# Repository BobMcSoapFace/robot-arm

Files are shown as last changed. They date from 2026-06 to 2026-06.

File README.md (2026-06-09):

# robot-arm
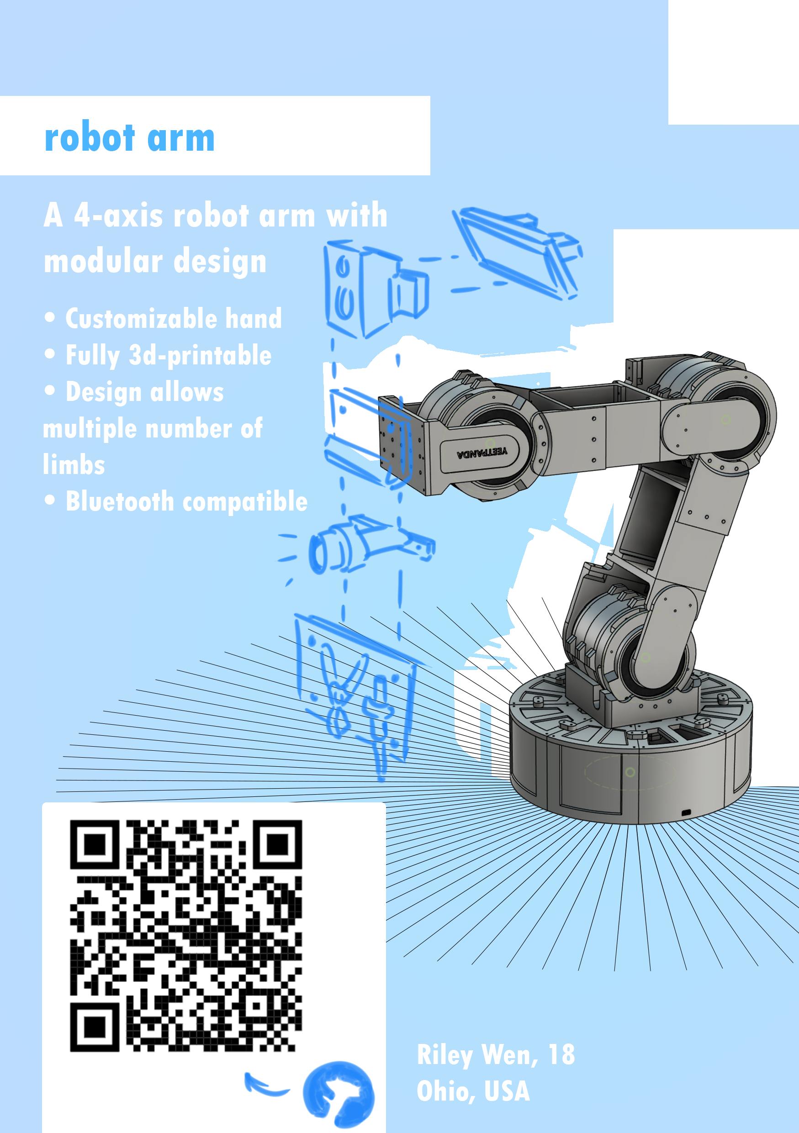
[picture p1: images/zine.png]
zine picture

robot-arm is a 4-axis robot arm designed with modularity in mind. Depending on the maximum torque output of the motors and maximum range of the I2C wires, this project can support numerous limbs with only minor changes in code. Currently, the code is fixed to allowing two limbs and a hand on the robot.

I built this project mostly to challenge myself to tackle more complicated electronic and mechanical designs, but also because most hobbyist robot arms focus on using claws or grippers to pick up objects. For this project, the minor change of a claw to a hand that can sense its own orientation as well as high gear ratios allows for supporting heavier objects such as displays and light fixtures. 

All materials can be found within BOM.csv.
# Electronics
## Limb Controller PCB
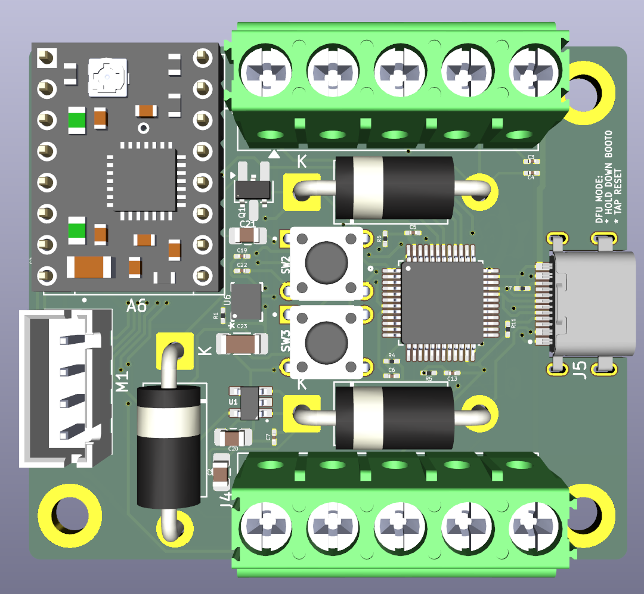
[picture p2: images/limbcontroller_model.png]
limb controller pcb 3d model

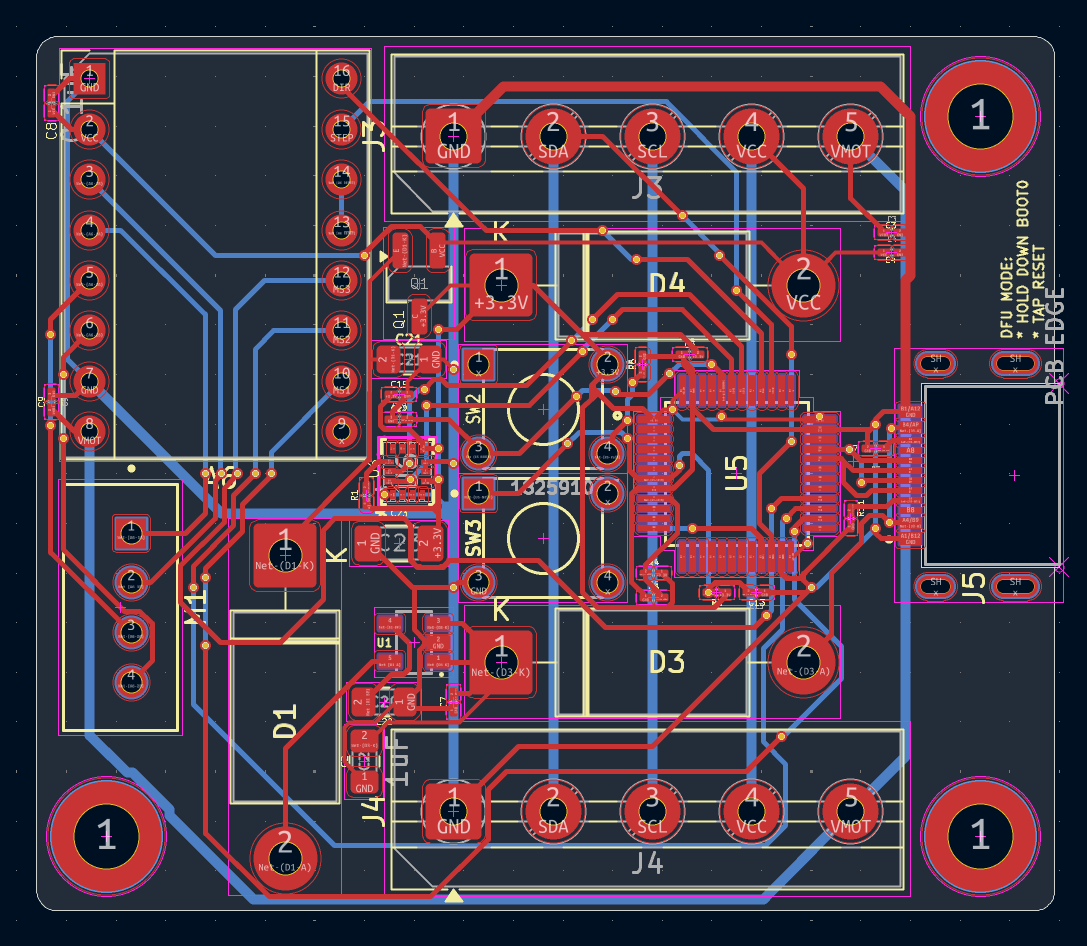
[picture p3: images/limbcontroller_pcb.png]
limb controller pcb footprint

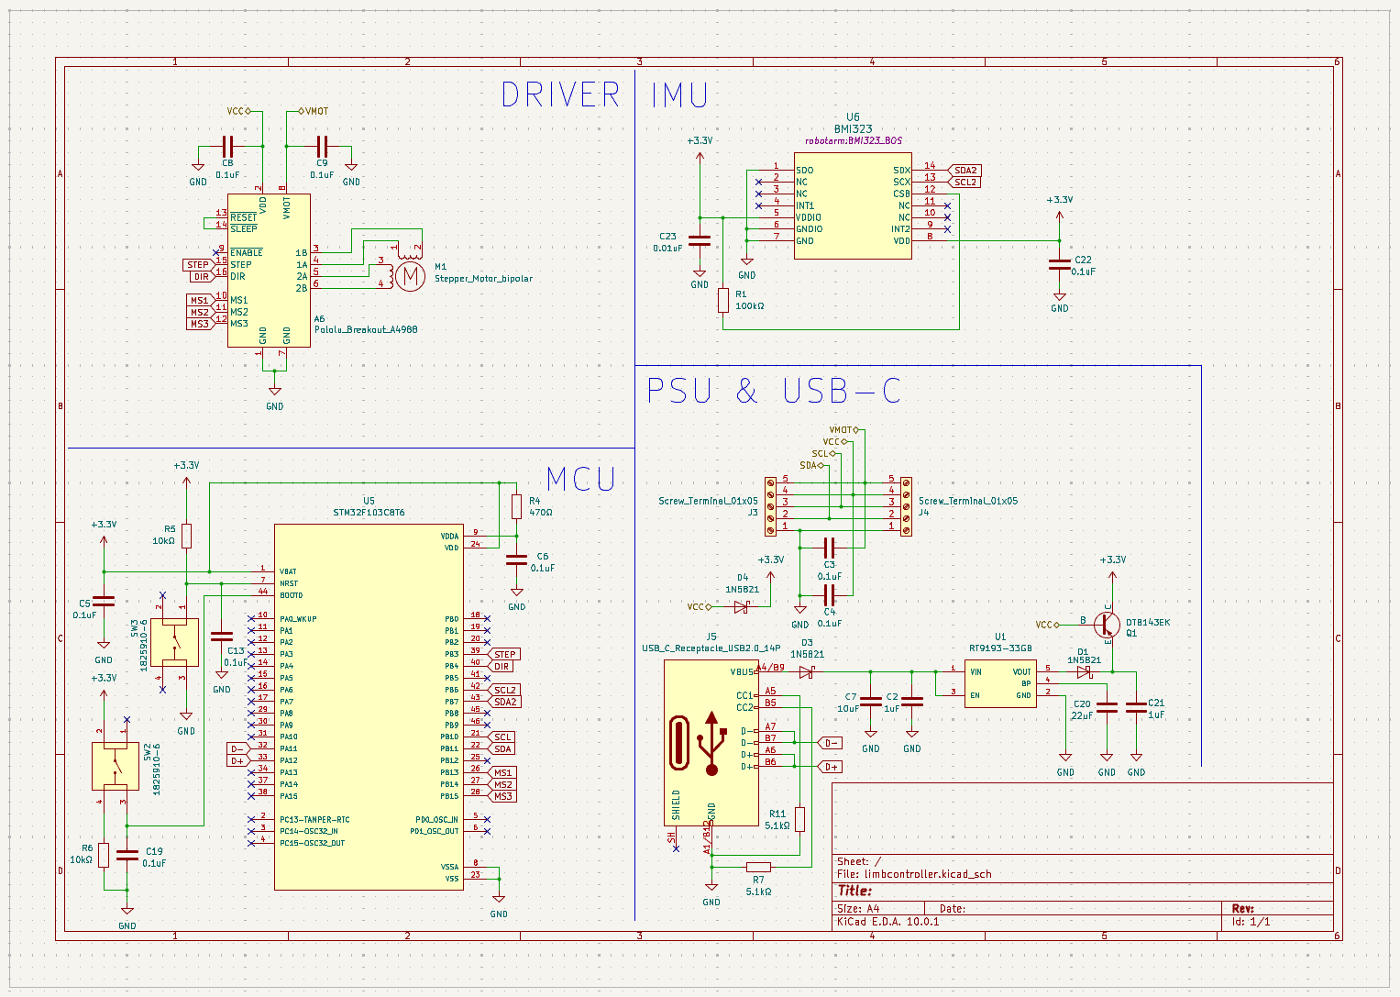
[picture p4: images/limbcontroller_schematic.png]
limb controller schematic

## Main Controller PCB
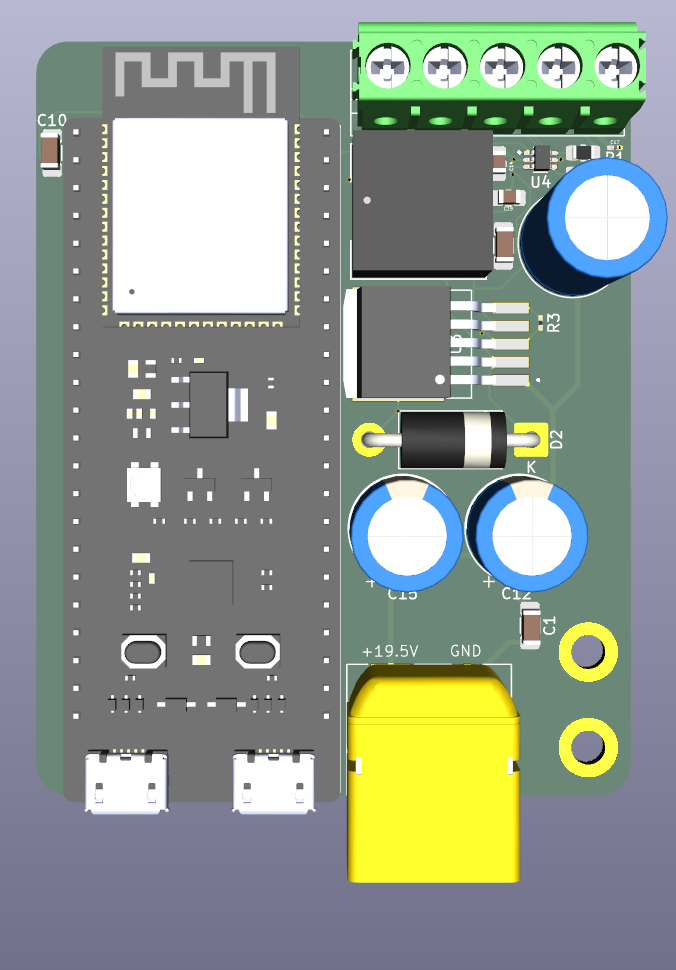
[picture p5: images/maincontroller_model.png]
main controller pcb 3d model

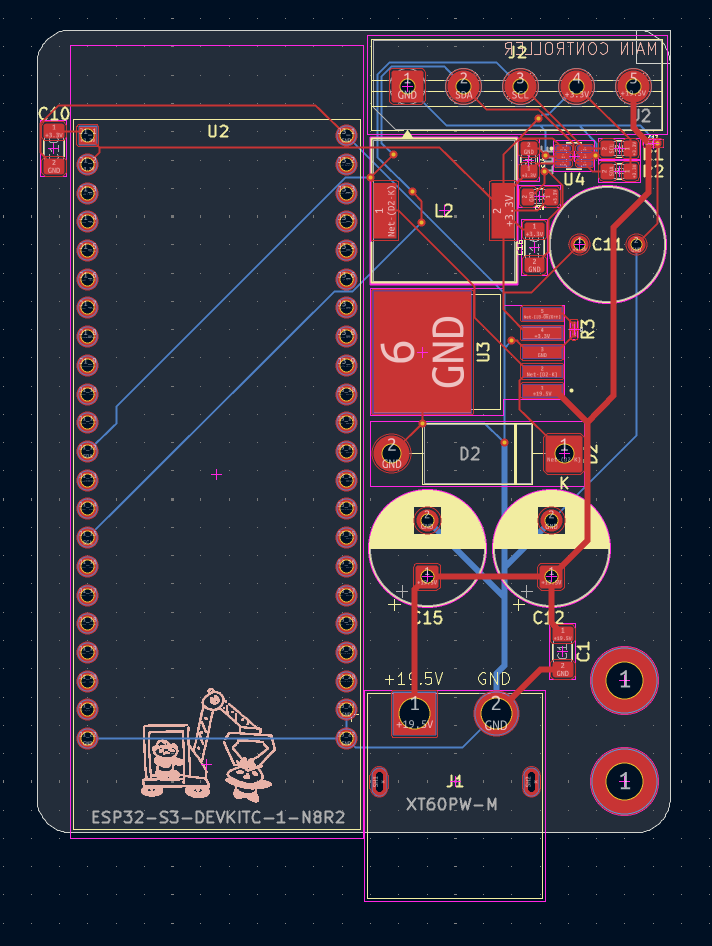
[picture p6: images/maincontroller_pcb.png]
main controller pcb footprint

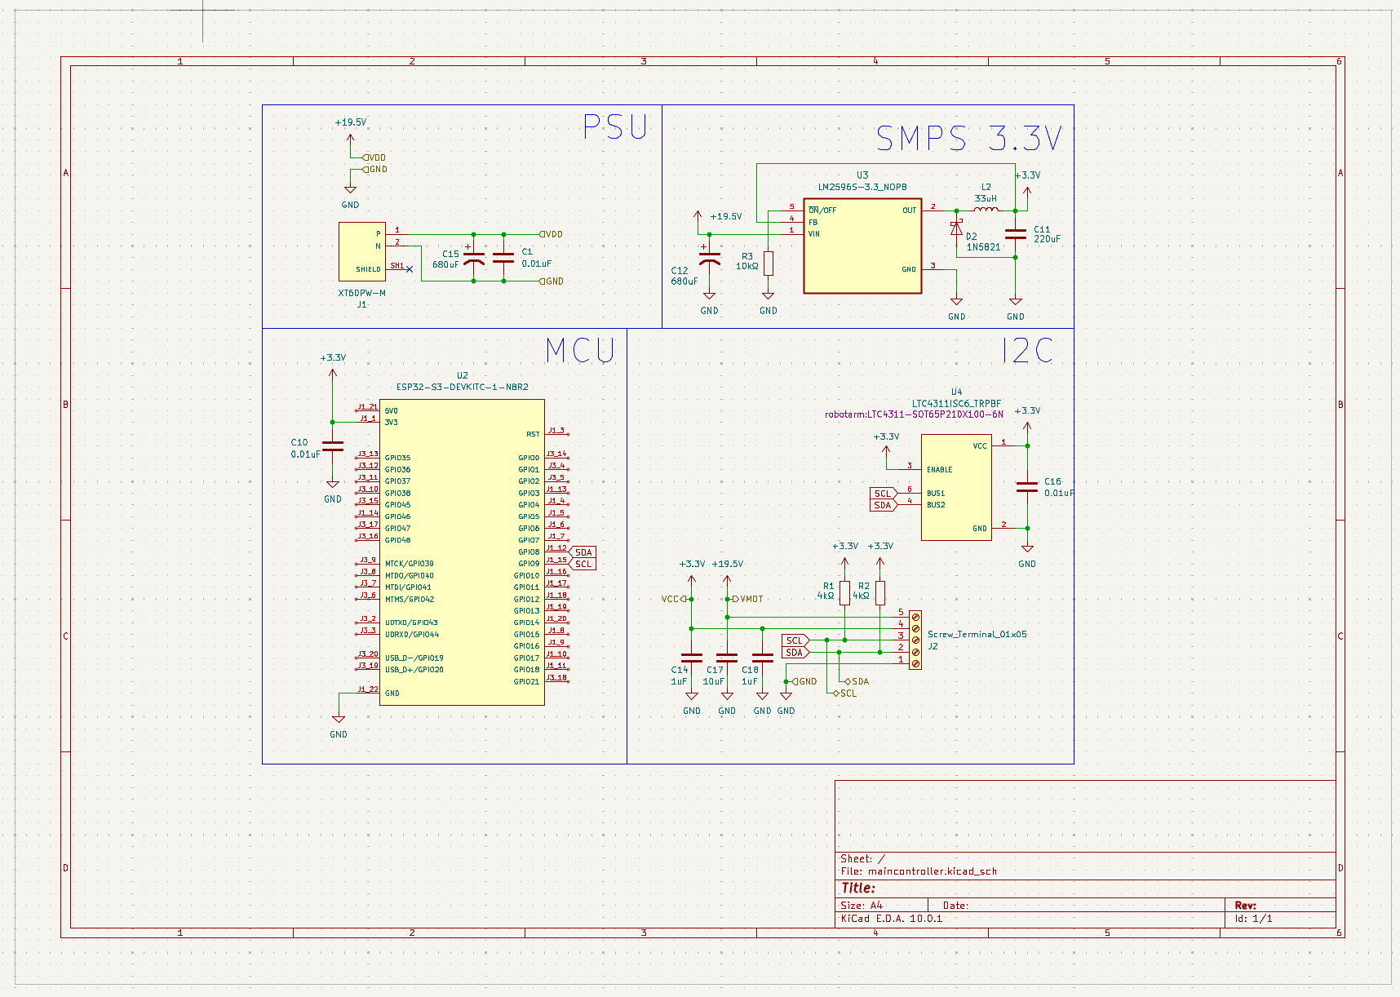
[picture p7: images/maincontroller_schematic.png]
main controller schematic

# Setup Instructions
## Electronics
First solder the components onto each board based on the diagrams above. For this project only 1 of the main controller boards are required, however 5 limb controller boards are required as well (with 1 not requiring a corresponding stepper motor nor driver).

On the main controller board, use PlatformIO to flash the main controller board using the code in /code/MainController. Since the board runs on an ESP32, flashing using other tools is likely be supported. Do not connect the XT60 while simultaneously flashing.

On the limb controller boards, use PlatformIO to flash via USB-C. While USB-C is connected, hold down the BOOT0 button and press the NRST button to enter DFU mode. Adjust the two parameters listed in the program based on which gearBox the controller is intended to be used for. Then, flash the firmware in /code/LimbController. 

## Assembly
Unless specified otherwise, all screws mentioned in the steps below refer to M4 1.6cm long screws meant for M4x6x6 inserts.
### Step 1 - baseSunGear
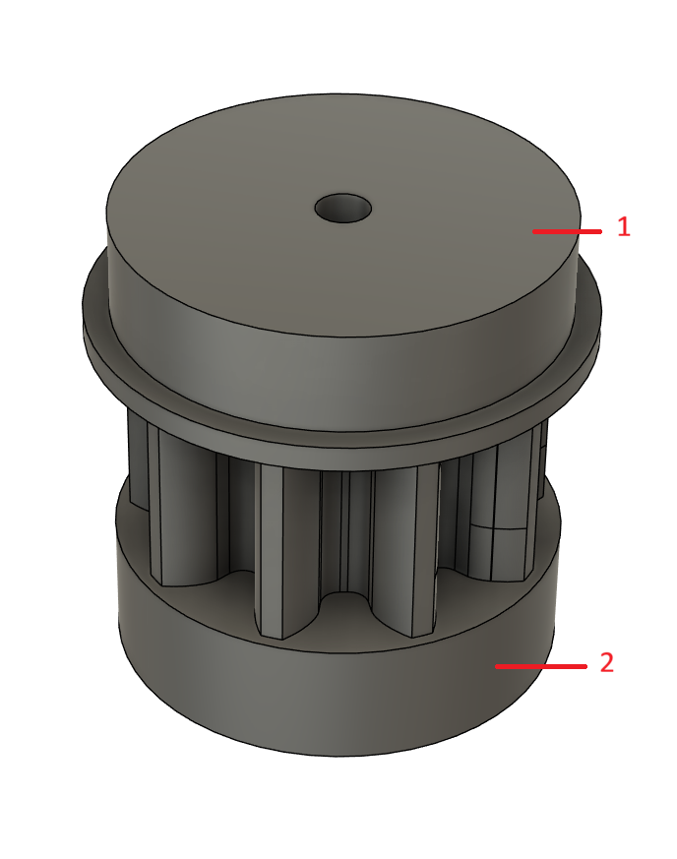
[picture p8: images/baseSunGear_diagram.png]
baseSunGear diagram

| Object | Print Quantity |
| --- | --- |
| 1 | 1x1 |
| 2 | 1x1 |
\* The "xN" represents the total number of gearboxes that require this part (meaning that a 3x4 quantity will need to be printed 12 times total)
1. For every hole about 0.7cm in diameter in every printable part, insert a M4x6x6 heat set threaded insert. 
   * In this part, only 1 threaded insert is required (the attachment between part 1 and part 2)
2. Screw part 1 to part 2.
3. Repeat this process 3 more times, for a total baseSunGear quantity of 4.
### Step 2 - gearReducer
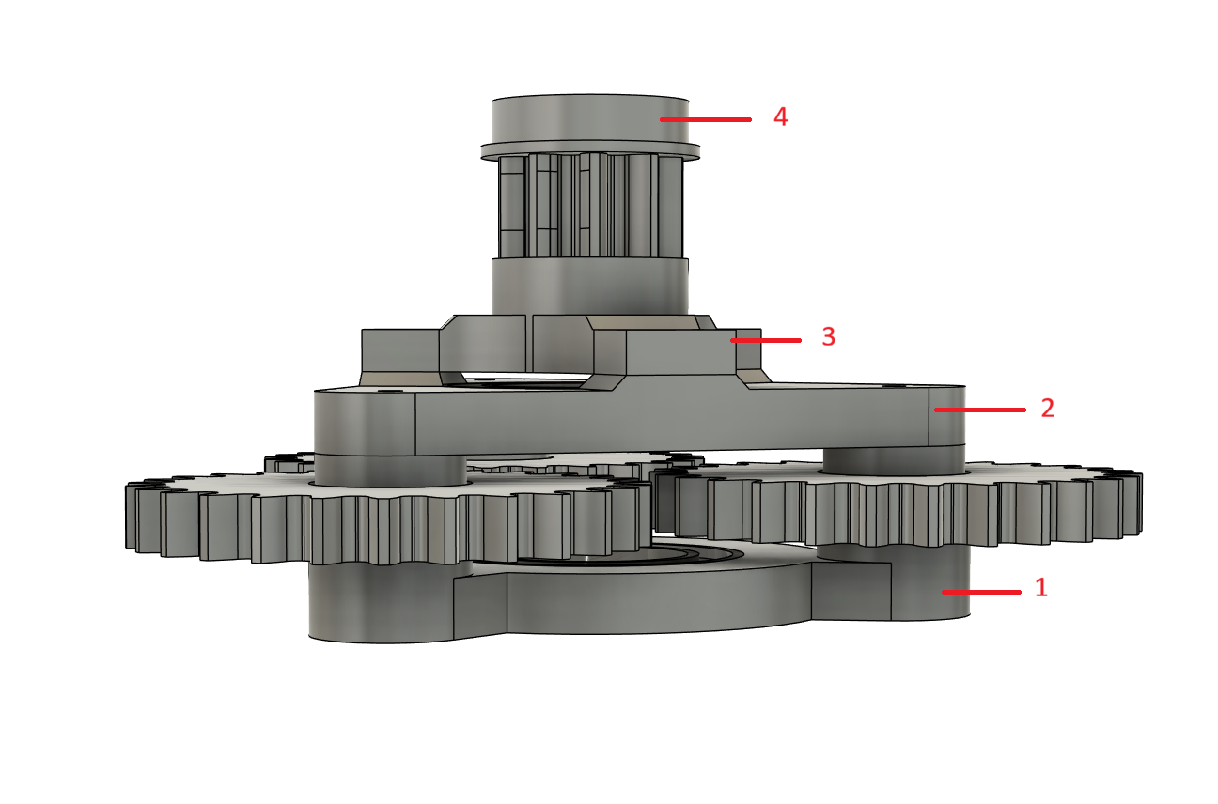
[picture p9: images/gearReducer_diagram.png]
gearReducer diagram

<ins>**Note: There is a baseSunGear supposed to be between parts 1 and 2 and the three gears, but is hidden for better clarity.**</ins>
| Object | Print Quantity |
| --- | --- |
| 1 | 1x4 |
| 2 | 1x4 |
| 3 | 1x4 |
| 4 | 1x4 |
| Gear (27 teeth) | 3x4 |
\* The "xN" represents the total number of gearboxes that require this part (meaning that a 3x4 quantity will need to be printed 12 times total)

1. For every hole about 0.7cm in diameter in every printable part, insert a M4x6x6 heat set threaded insert. 
2. Using a hammer or other means, press fit a 6907ZZ bearing into part 1.
3. For each of the three 27 tooth gears, press fit a 6805 bearing into its cavity.
4. With the smaller hole side facing upwards, place each of the 3 gears on the poles of part 1.
5. Press fit a 6907ZZ bearing into the center hole of part 2.
6. With the baseSunGear's circular side of its part 2, press fit the baseSunGear into the 6907ZZ bearing of part 1 (the baseSunGear protruding upwards and aligning its teeth with the three gears).
7. Press fit part 2's 6907ZZ bearing on the baseSunGear's part 1.
7. Screw part 2 to part 1.
8. Screw part 3 to part 2.
9. Screw part 4 to part 3.
10. Repeat this process 3 more times, for a total gearReducer quantity of 4.
### Step 3 - gearReducerOutput
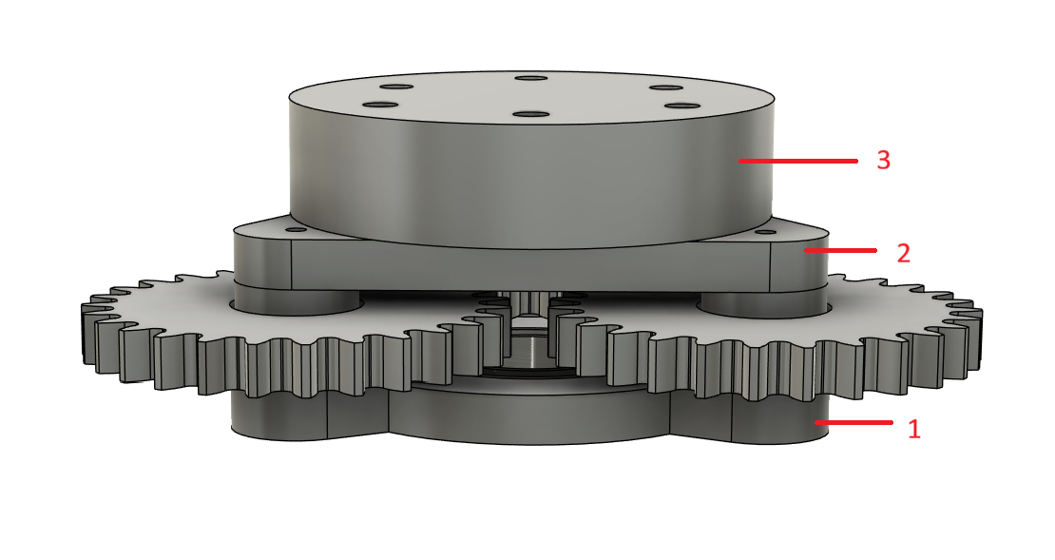
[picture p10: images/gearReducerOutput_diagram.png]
gearReducerOutput digram

| Object | Print Quantity |
| --- | --- |
| 1 | 1x4 |
| 2 | 1x4 |
| 3 | 1x4 |
| Gear (27 teeth) | 3x4 |
\* The "xN" represents the total number of gearboxes that require this part (meaning that a 3x4 quantity will need to be printed 12 times total)
1. For every hole about 0.7cm in diameter in every printable part, insert a M4x6x6 heat set threaded insert. 
2. Using a hammer or other means, press fit a 6907ZZ bearing into part 1.
3. For each of the three 27 tooth gears, press fit a 6805 bearing into its cavity.
4. With the smaller hole side facing upwards, place each of the 3 gears on the poles of part 1.
5. Press fit a 6907ZZ bearing into the center hole of part 2.
6. Screw part 2 to part 1.
7. Screw part 3 to part 2.
9. Repeat this process 3 more times, for a total gearReducerOutput quantity of 4.
### Step 4 - gearBox
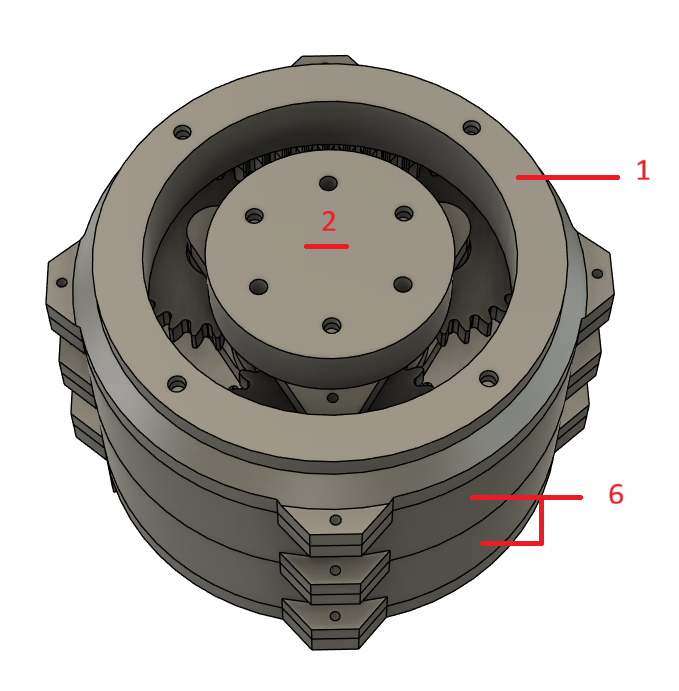
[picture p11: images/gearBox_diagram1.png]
gearBox diagram 1

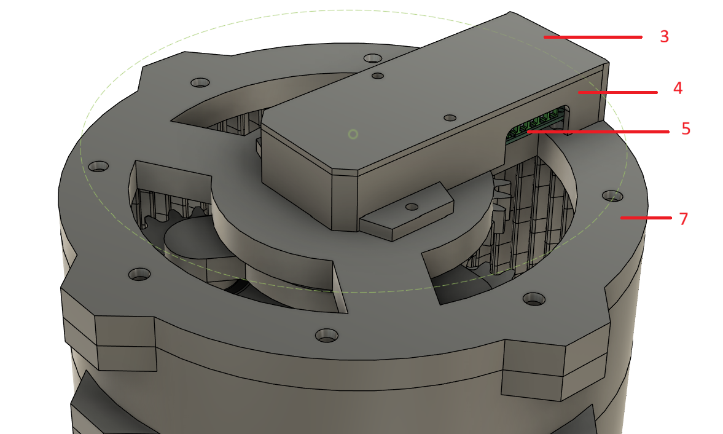
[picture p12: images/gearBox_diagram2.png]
gearBox diagram 2

<ins>**Note: There is a 6020 bearing supposed to be between parts 1 and 2, but is hidden for better clarity.**</ins>
| Object | Print Quantity |
| --- | --- |
| 1 | 1x4 |
| 2 | 1x4 |
| 3 | 1x4 |
| 4 | 1x4 |
| 5 | 1x4 |
| 6 | 2x4 |
| gearReducerOutput | 1x4 |
| gearReducer | 1x4 |
| baseSunGear | 1x4 |
| Nema17 Stepper Motor | 1x4 |

1. For every hole about 0.7cm in diameter in every printable part, insert a M4x6x6 heat set threaded insert. 
2. Screw the two part 6's together using the outer brackets.
3. Screw the joined part 6's to part 7.
4. Screw part 4 to part 7.
5. Screw part 5 to part 7, with the screw terminals being accessible from the provided holes.
6. Align the asymmetrical shaft of the Nema17 stepper motor to the gearReducer's baseSunGear corresponding hole of the same shape, attaching the two objects.
7. Lower the gearReducer with the Nema17 into the ring gears, with the Nema17 aligning with the cavity provided by part 4.
8. Once the Nema17 is inside the cavity, screw part 3 to part 4, blocking the Nema17 from falling through.
9. Unscrew part 4 from part 3 for the gearReducer, and unscrew parts 2 and 3 from gearReducerOutput's part 1.
10. Lower the gearReducerOutput into the ring gear, aligning the 27 teeth gears with the base gear in the middle.
11. Screw back part 4 to part 3 for the gearReducer
12. Press fit the gearReducer's part 4 with the 6907ZZ bearing of the deattached gearReducerOutput's part 2, then screw parts 2 and 3 back to gearReducerOutput's part 1.
13. Press fit a 6020 bearing onto the gearbox's part 1, then press fit the bearing onto the gearReducerOutput's output cylinder (marked part 2)
14. Repeat 3 more times, for a total of 4 gearboxes.
### Step 5 - limb
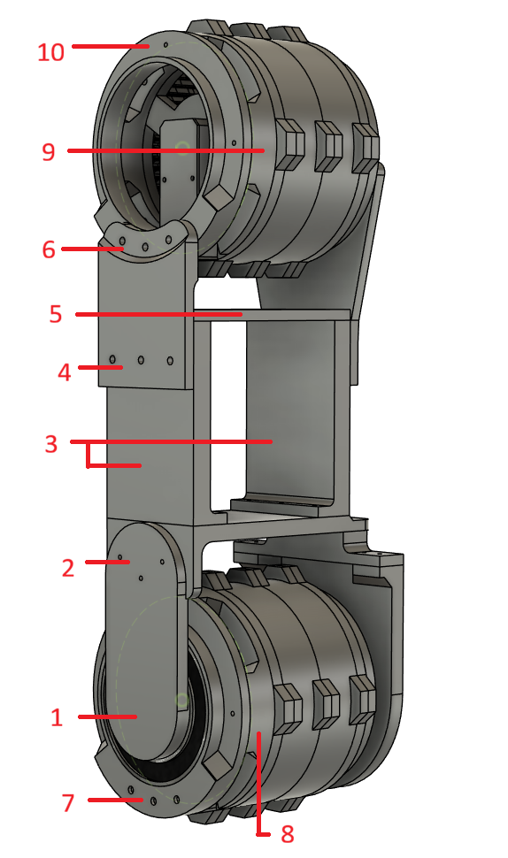
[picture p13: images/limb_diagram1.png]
limb diagram 1

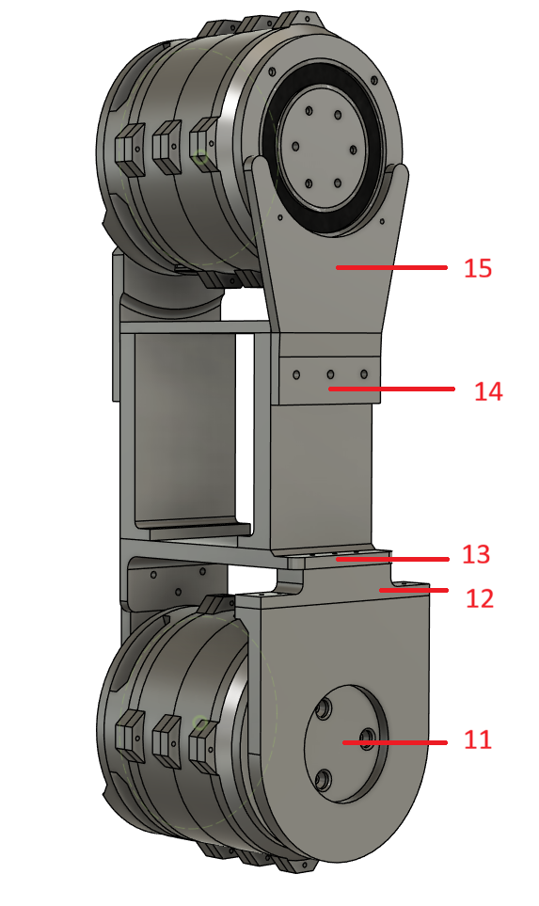
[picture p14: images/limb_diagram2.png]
limb diagram 2

| Object | Print Quantity |
| --- | --- |
| 1 | 1x2 |
| 3 | 2x2 |
| 4 | 1x2 |
| 5 | 1x2 |
| 7 | 1x2 |
| 8 | 1x2 |
| 9 | 1x2 |
| 10 | 1x2 |
| 11 | 1x2 |
| 12 | 1x2 |
| 13 | 1x2 |
| 14 | 1x2 |
\*Note that parts 15 and 6 are the same parts as 14 and 5 respectively.
1. For every hole about 0.7cm in diameter in every printable part, insert a M4x6x6 heat set threaded insert. 
2. On a gearbox, screw part 8 to the side with the controller.
3. Press fit a 6020 bearing to part 7, then screw part 7 to part 8.
4. Press fit part 1 to the bearing.
5. On the side of the gearbox outputting rotation, screw part 11 to the gearbox's output.
6. Screw part 12 to part 11.
7. Screw part 13 to parts 12 and 2.
8. Screw the two part 3's to part 13.
9. Screw part 5 to the two part 3's.
10. Screw part 4 to the part 3 on the side of the gearbox's controller.
11. Screw part 14 to the part 3 on the side of the gearbox's output.
12. Screw parts 14 and 4 to a second gearbox.
13. Repeat the steps above for a second limb, using the newly attached gearbox as the base (used in steps 2 and 5).
### Step 6 - base
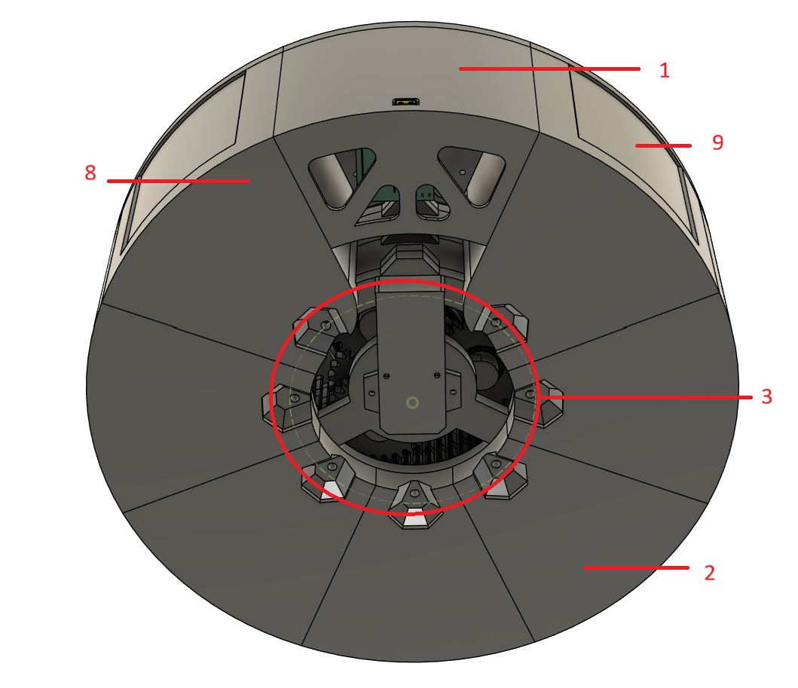
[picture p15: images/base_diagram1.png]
base diagram 1

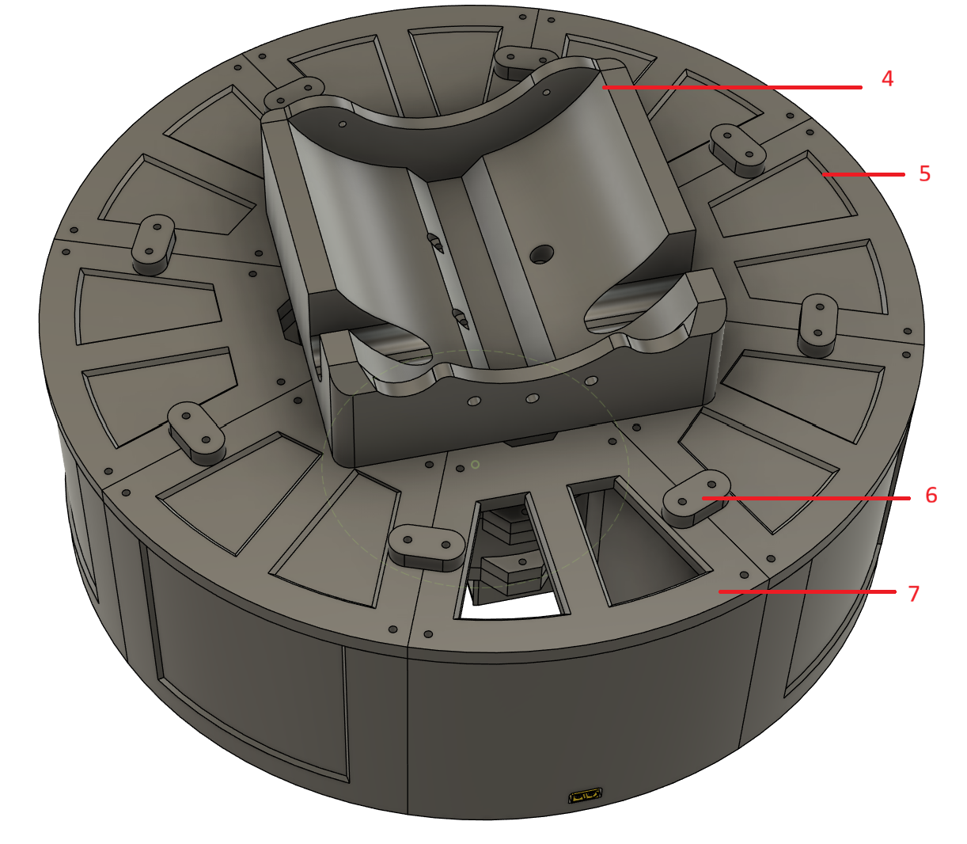
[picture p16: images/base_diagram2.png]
base diagram 2

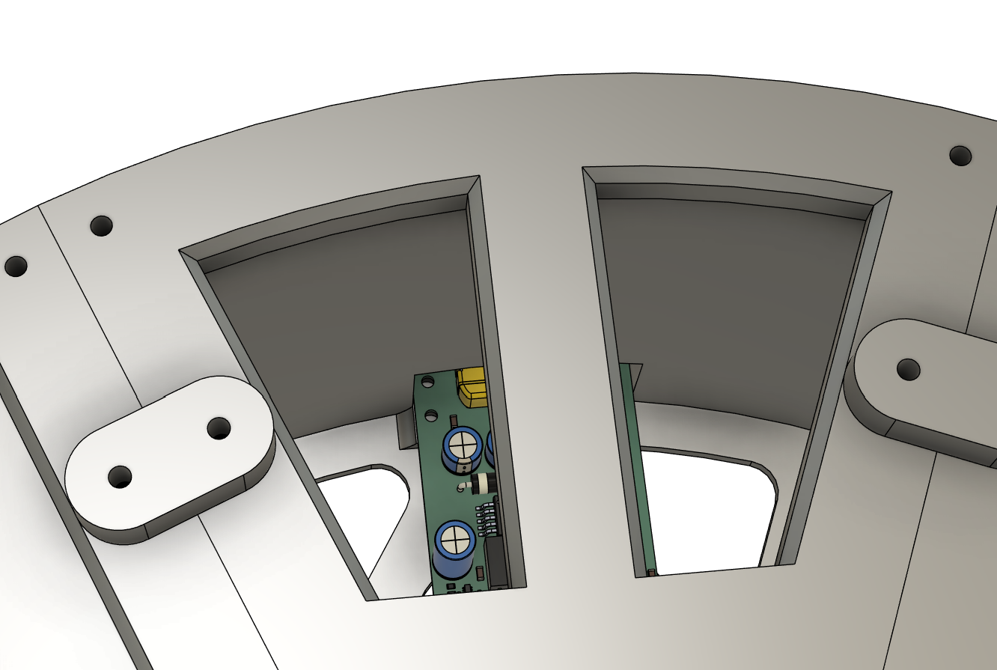
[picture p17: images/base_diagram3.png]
base diagram 3

| Object | Print Quantity |
| --- | --- |
| 1 | 1x1 |
| 2 | 7x1 |
| 4 | 1x1 |
| 5 | 7x1 |
| 6 | 8x1 |
| 7 | 1x1 |
| 8 | 1x1 |
| 9 | 1x1 |

\*Note that parts 15 and 6 are the same parts as 14 and 5 respectively.
1. For every hole about 0.7cm in diameter in every printable part, insert a M4x6x6 heat set threaded insert.
2. Using the inserts indicated by the region labeled #3, screw in 7 part 2's, avoiding the area covered by the gearbox controller.
3. To increase arm stability during movement, insert a heavy filler (e.g sand or gravel) or other similar heavy objects in equal distribution among the part 2's.
4. Screw a part 5 to each of the part 2's (7 total).
5. Screw a main controller PCB to part 1
6. Screw part 1 to the gearbox, and then screw part 7 to part 1.
7. Screw 8 part 6's to connect each of the part 7's together. 
7. With a gearbox in the middle and output side facing upwards, screw part 4 to the gearbox using the three holes.
### Step 7 - hand
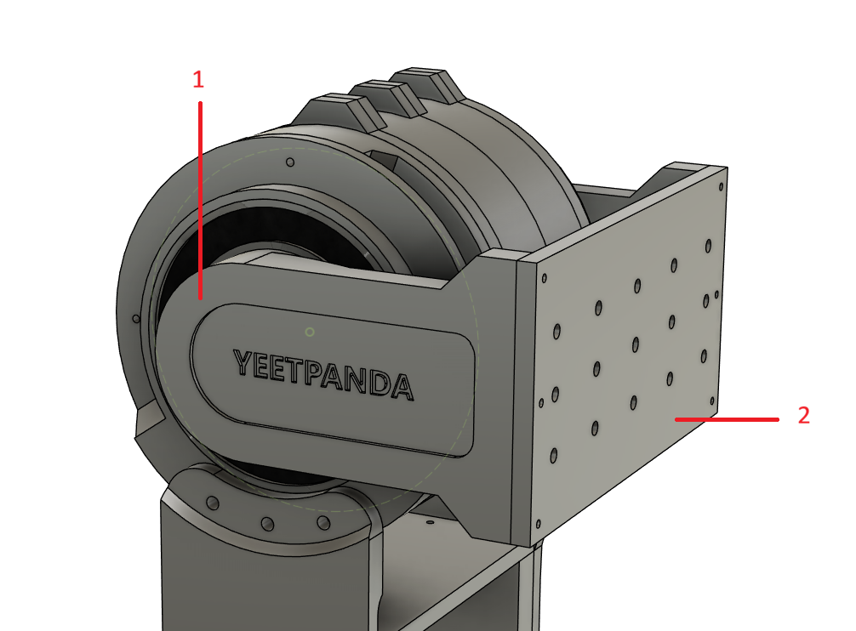
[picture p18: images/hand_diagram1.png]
hand diagram 1

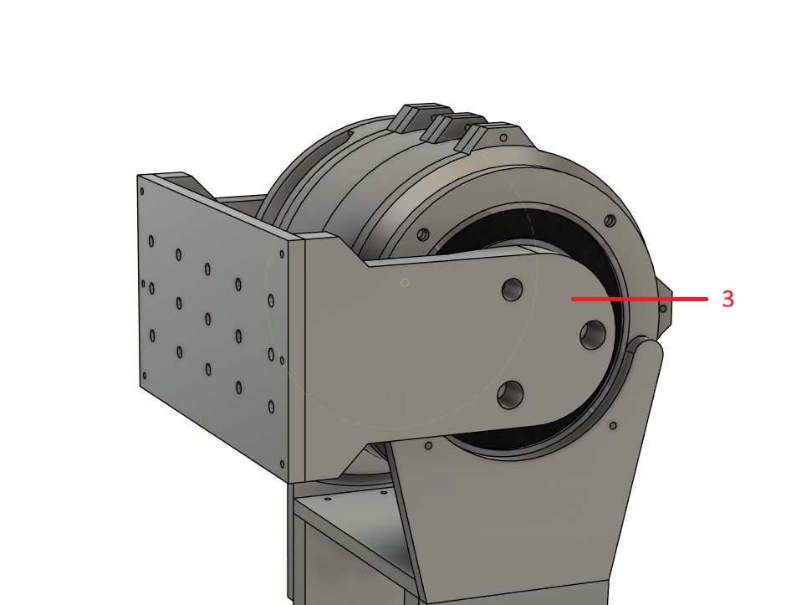
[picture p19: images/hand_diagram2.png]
hand diagram 2

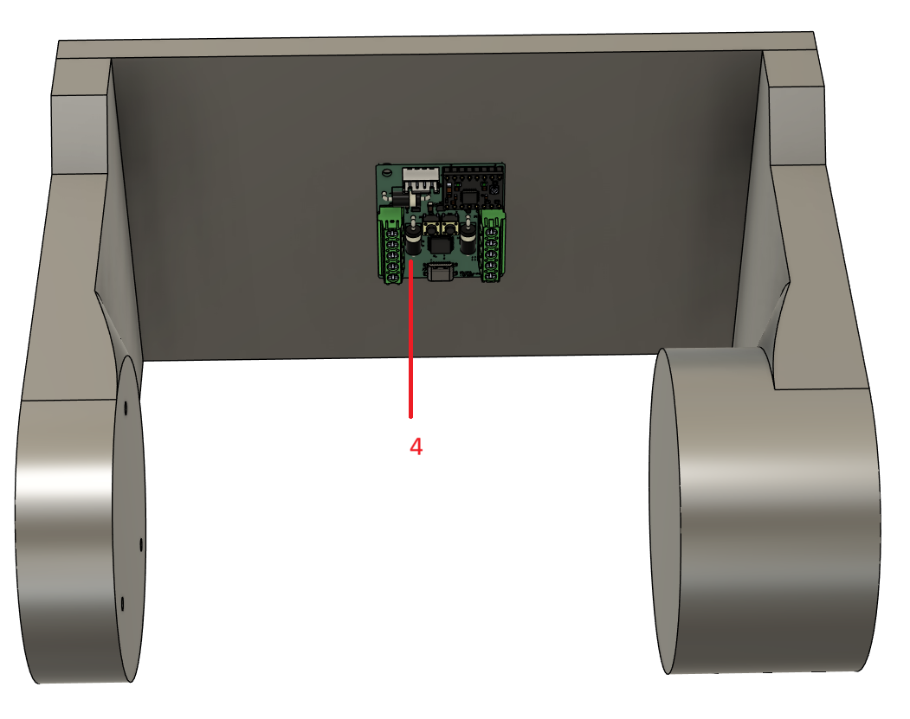
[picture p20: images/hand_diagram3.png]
hand diagram 3


| Object | Print Quantity |
| --- | --- |
| 1 | 1x1 |
| 2 | 1x1 |
| 3 | 1x1 |

1. For every hole about 0.7cm in diameter in every printable part, insert a M4x6x6 heat set threaded insert.
2. Screw part 3 to the output of the last limb's gearbox output.
3. Press fit a 6020 bearing to the last limb's gearbox controller side on the attached part, then press fit part 1 into the bearing.
4. Screw parts 1 and 3 together with part 2.
5. Screw the limb controller (part 4) to part 2.
   * Note that on this controller, an A4988 motor driver is not required.
### Step 8 - Connecting Limbs to Base
1. Using the screw terminals on each board, connect wires from the main controller to the limb controller in the base on one side. On the other side of the limb controller's screw terminals, connect more wires to the next gearbox's limb controllers, repeating the process for each controller until the hand's controller is connected.
   * You may have to unscrew some parts connecting to the gearbox to be able to reach the screw terminals.
   * Low capacitance wires are preferred, ex. solid core
   * Each terminal in the screw terminals on the limb controller are connected directly to the parallel terminal on the other screw terminal; simply connect the same terminals with each other
2. Lower the side of the first limb's initial gearbox with the output side facing the base's part 4 side with two holes for screws.
3. Deattach the limb's part 11 from the gearbox and part 12, then secure the gearbox in the base's part 4 by screwing in the two holes. Reattach part 11 afterwards.
4. On the other side of the gearbox, secure the gearbox with the three screw holes on base 4.

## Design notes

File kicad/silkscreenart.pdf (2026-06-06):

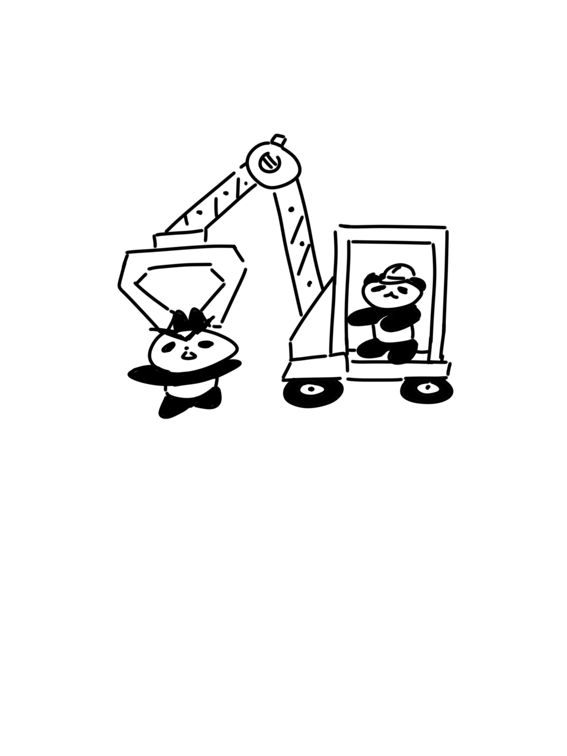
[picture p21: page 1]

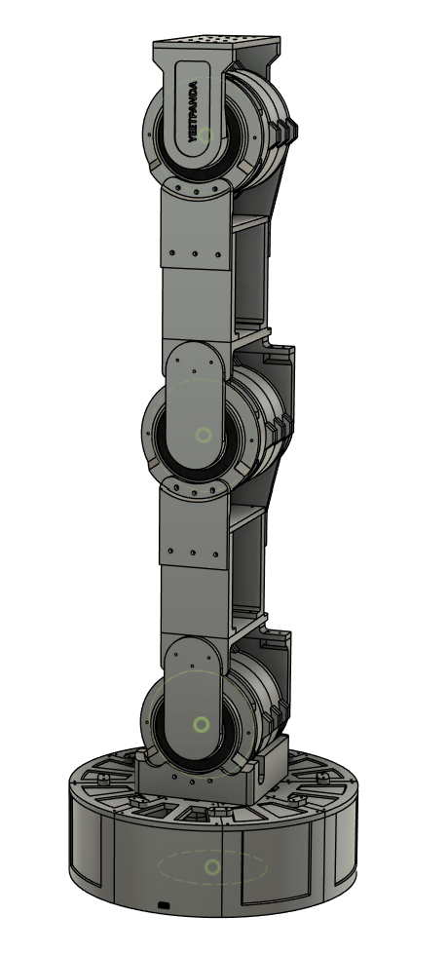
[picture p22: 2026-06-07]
images/arm_diagram2.png

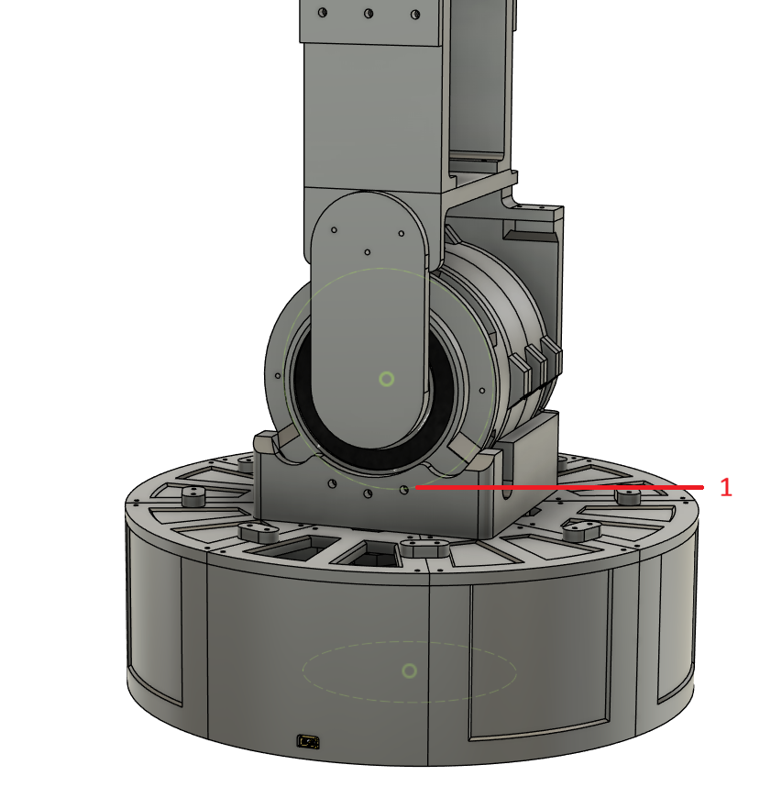
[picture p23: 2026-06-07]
images/arm_diagram1.png

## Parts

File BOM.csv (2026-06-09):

Name | Purchase Quantity | Required Pcs | Link | Unit Price | Total Price
19.5V 10.3A Power Adapter | 1 |  | https://www.amazon.com/TAIFU-Adapter-Compatible-Charger-Balance/dp/B0DNJDK5JN | $21.99 | $21.99
LM2596S-3.3V | 1 |  | https://www.digikey.com/en/products/detail/evvo/LM2596S-3-3-EV/24370077 | $1.31 | $1.31
ESP32 Devkit V1 | 1 |  | https://www.aliexpress.us/item/3256808315965945.html?src=google&gatewayAdapt=glo2usa | $4.09 | $4.09
XT60PW-M (Male) | 1 |  | https://www.aliexpress.us/item/2255799820907812.html?src=google&gatewayAdapt=glo2usa | $3.00 | $3.00
A4988 Stepper Motor Driver | 4 |  | https://www.alibaba.com/product-detail/3D-Printed-A4988-Red-Stepper-Motor_1601242133819.html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 | $0.60 | $2.40
STM32F103C8T7TR | 5 |  | https://www.alibaba.com/product-detail/STM32F103C8T7-MCU-Microcontroller-Integrated-Circuit-New_1601672982059.html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 | $2.20 | $11.00
LTC4311ISC6 TRPBF | 1 |  | https://www.digikey.com/en/products/detail/analog-devices-inc/LTC4311ISC6-TRPBF/1814494 | $5.40 | $5.40
BMI323 | 5 |  | https://www.digikey.com/en/products/detail/bosch-sensortec/BMI323/16719593 | $3.69 | $18.45
PNP Transistor DTB143EKT146 | 5 |  | https://www.digikey.com/en/products/detail/rohm-semiconductor/DTB143EKT146/658864 | $0.57 | $2.85
470 Ohm Resistor | 5 |  | https://www.digikey.com/en/products/detail/rohm-semiconductor/KTR03EZPJ471/2288583?gclsrc=aw.ds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 | $0.15 | $0.75
4k Ohm Resistor | 2 |  | https://www.digikey.com/en/products/detail/stackpole-electronics-inc/RNCF0805BTS4K00/9690208 | $0.15 | $0.30
5.1k Ohm Resistor | 10 |  | https://www.digikey.com/en/products/detail/yageo/RC0603FR-075K1L/727268 | $0.10 | $1.00
10k Ohm Resistor | 11 |  | https://www.digikey.com/en/products/detail/yageo/RC0603FR-0710KL/726880 | $0.10 | $1.10
100k Ohm Resistor | 5 |  | https://www.digikey.com/en/products/detail/stackpole-electronics-inc/RGC0603FTC100R/1715582?gclsrc=aw.ds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 | $0.14 | $0.70
1N5821 Diode | 16 |  | https://www.digikey.com/en/products/detail/taiwan-semiconductor-corporation/1N5821/7366595 | $0.71 | $11.36
SPST Switch | 10 |  | https://www.digikey.com/en/products/detail/te-connectivity-alcoswitch-switches/1825910-6/1632536 | $0.13 | $1.30
0.01uF Capacitor | 8 |  | https://www.digikey.com/en/products/detail/kemet/C1206C103K1RACTU/411235 | $0.17 | $1.36
0.1uF Capacitor | 45 |  | https://www.digikey.com/en/products/detail/samsung-electro-mechanics/CL10B104KB8NNNC/3886658 | $0.02 | $0.68
1uF Capacitor | 12 |  | https://www.digikey.com/en/products/detail/murata-electronics/GRM155R61E105KA12D/4905139 | $0.03 | $0.35
10uF Capacitor | 6 |  | https://www.digikey.com/en/products/detail/kyocera-avx/CM105X6S106M25AT/17827475?gclsrc=aw.ds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 | $0.35 | $2.10
22uF Capacitor | 5 |  | https://www.digikey.com/en/products/detail/murata-electronics/GRM21BR61E226ME44K/4905534?gclsrc=aw.ds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 | $0.35 | $1.75
680uF Polarized Capacitor | 2 |  | https://www.digikey.com/en/products/detail/kyocera-avx/REF1020681M025K/20096679?gclsrc=aw.ds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 | $0.62 | $1.24
220uF Capacitor | 1 |  | https://www.digikey.com/en/products/detail/tdk/B41856C6227M000/6159972?gclsrc=aw.ds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 | $0.76 | $0.76
33uH Inductor | 1 |  | https://www.digikey.com/en/products/detail/eaton-electronics-division/DR127-330-R/667173 | $0.85 | $0.85
17HS4401S Nema 17 Stepper Motor | 4 |  | https://www.alibaba.com/product-detail/Hanpose-Stepper-Motor-40N-cm-1_1600212040912.html | $4.50 | $18.00
USB-C Receptacle | 5 |  | https://www.digikey.com/en/products/detail/wec/2340901-1/18856002 | $0.42 | $2.10
RT9193 | 5 |  | https://www.digikey.com/en/products/detail/richtek-usa-inc/RT9193-33GB/2470048 | $0.41 | $2.05
5x1 Screw Terminal | 11 |  | https://www.digikey.com/en/products/detail/phoenix-contact/1935190/568617 | $1.28 | $14.08
B4B-XH-A | 4 |  | https://www.digikey.com/en/products/detail/jst-sales-america-inc/B4B-XH-A/1651047 | $0.17 | $0.68
100pcs M4x6x6 Heat Threaded Inserts | 3 | 279 | https://www.amazon.com/Aoserge-100Pcs-Brass-Heat-Inserts/dp/B0FM3XZZ56?adgrpid=187992247084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 | $6.49 | $19.47
10pcs 6805-2RS | 3 | 24 | https://www.amazon.com/6805-2RS-Bearings-Miniature-Section-Bearing/dp/B0DS59TSHD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 | $12.49 | $37.47
10pcs 6907ZZ Deep Groove Ball Bearings | 2 | 16 | https://www.amazon.com/HiPicco-6907ZZ-Bearings-Shielded-Pre-Lubricated/dp/B0CRLF5NZY?s=industrial | $21.89 | $43.78
6020-2RS | 6 | 6 | https://www.amazon.com/80x125x22mm-Pre-Lubricated-Performance-Effective-Bearings/dp/B0CGLRM1JS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 | $19.99 | $119.94
Total Electrical Parts Price |  |  |  |  | $132.99
Total Mechanical Parts Price |  |  |  |  | $220.66
Total Price |  |  |  |  | $353.65

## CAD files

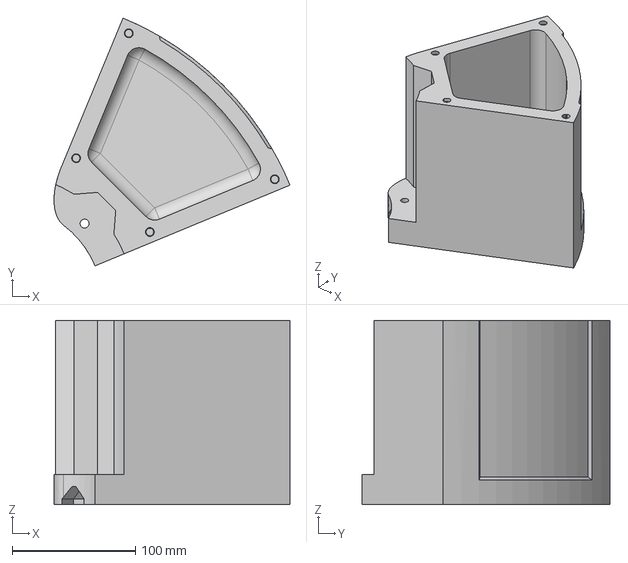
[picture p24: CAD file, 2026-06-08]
model/base/obj8.step
191.2 x 200.7 x 149.2 mm

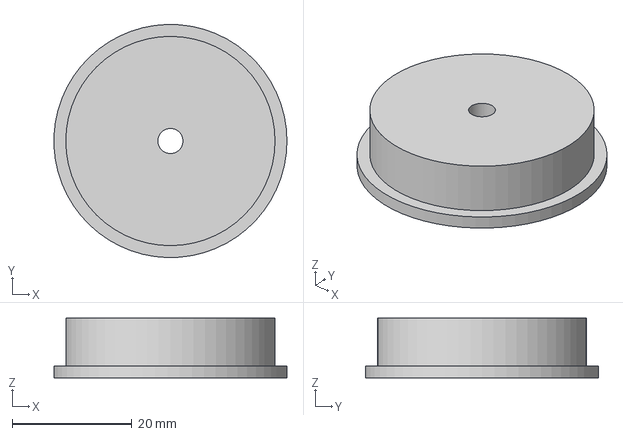
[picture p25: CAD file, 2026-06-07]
model/baseSunGear/obj1.step
39.0 x 39.0 x 10.0 mm

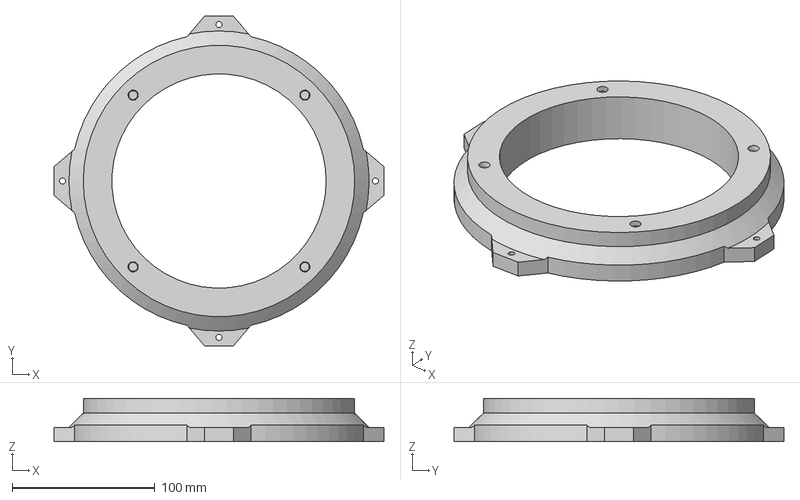
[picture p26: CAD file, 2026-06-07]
model/gearBox/obj1.step
231.0 x 231.0 x 30.2 mm

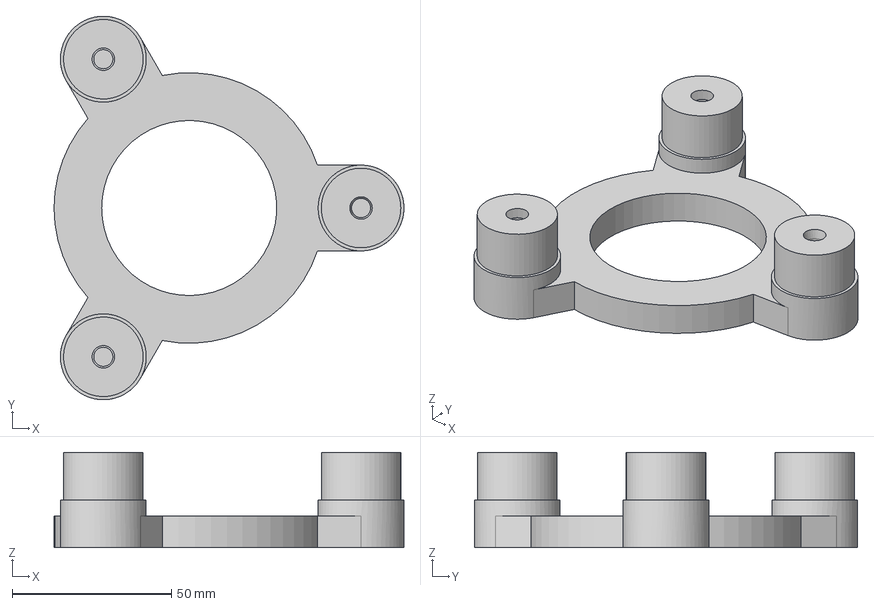
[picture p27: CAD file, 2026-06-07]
model/gearReducer/obj1.step
110.0 x 120.5 x 30.0 mm

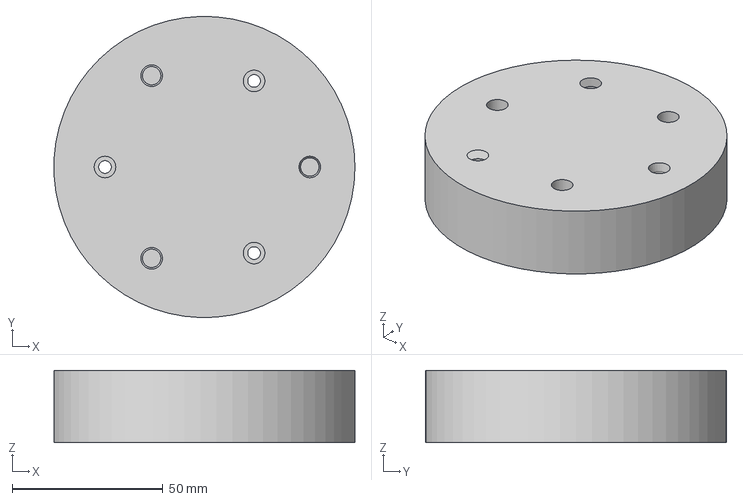
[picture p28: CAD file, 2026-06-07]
model/gearReducerOutput/obj3.step
99.9 x 100.0 x 24.0 mm

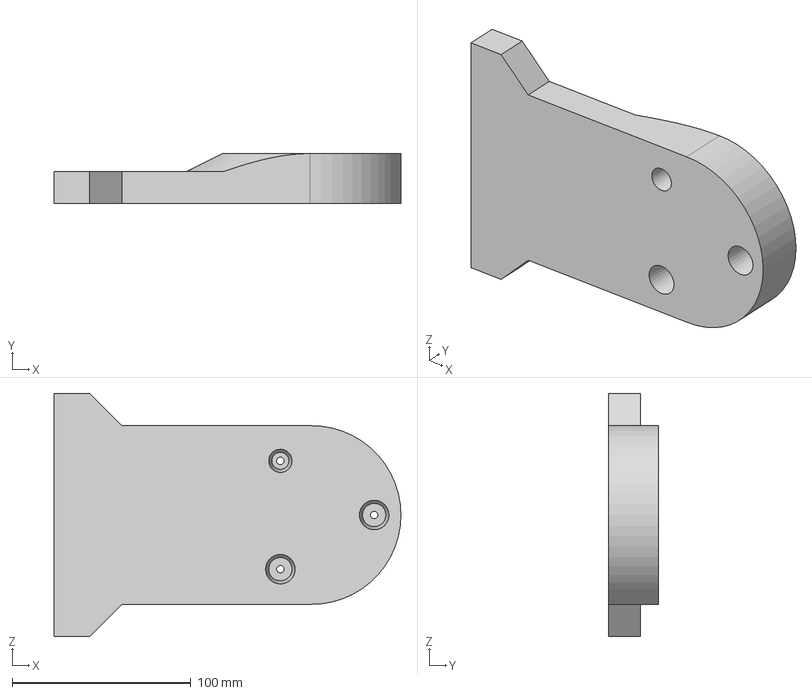
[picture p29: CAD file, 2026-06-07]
model/hand/obj3.step
194.2 x 28.0 x 136.0 mm

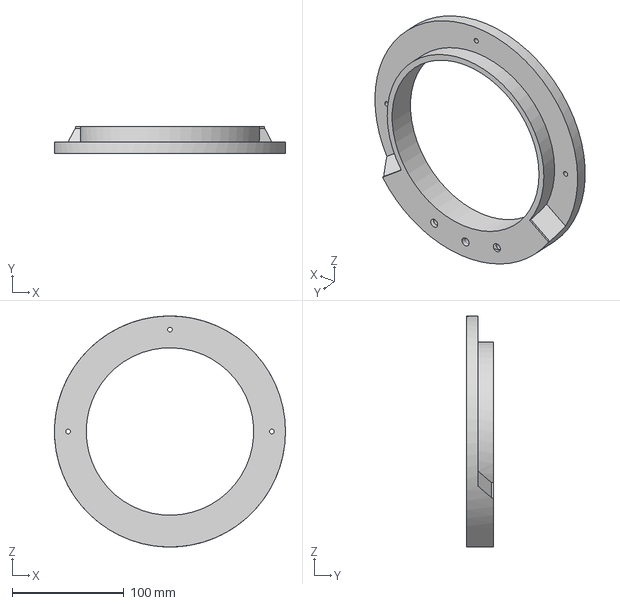
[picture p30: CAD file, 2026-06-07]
model/limb/obj10.step
207.0 x 24.0 x 207.0 mm

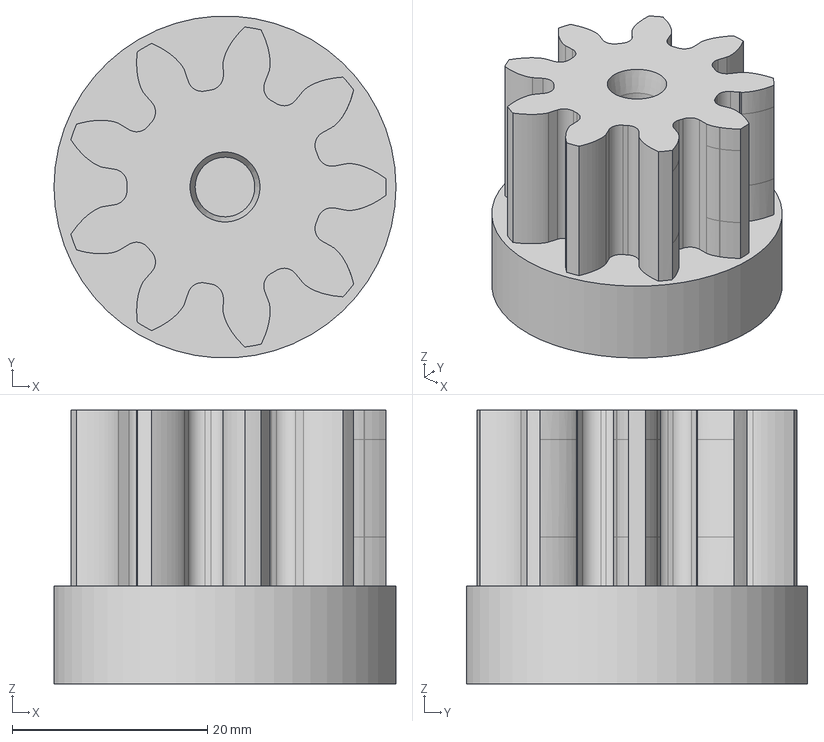
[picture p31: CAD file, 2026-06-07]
model/baseSunGear/obj2.step
35.0 x 34.9 x 28.0 mm

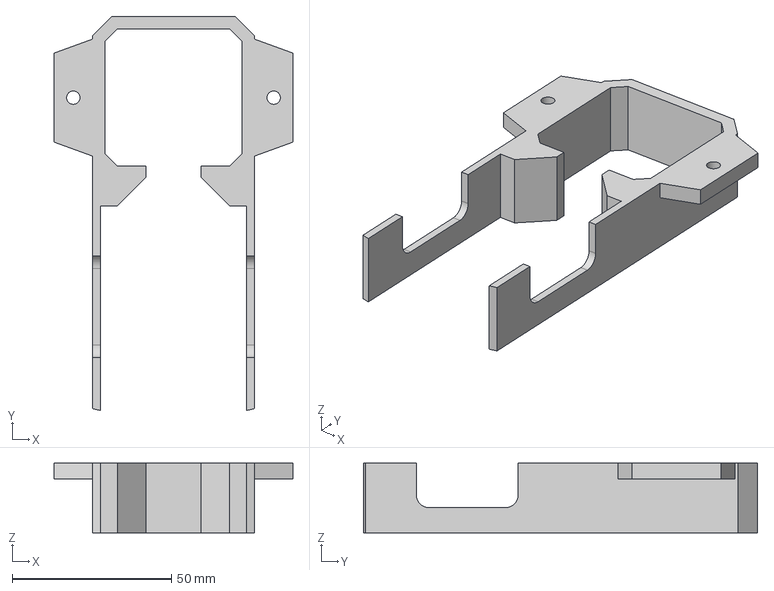
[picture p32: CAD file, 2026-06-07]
model/gearBox/obj4.step
75.0 x 123.8 x 21.9 mm

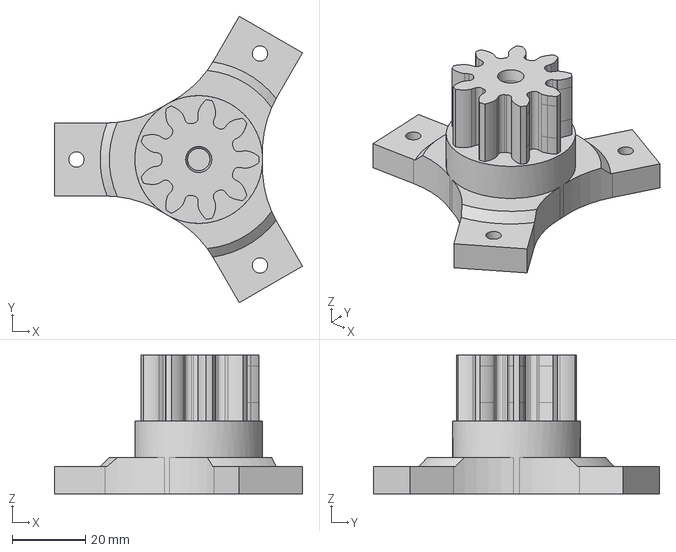
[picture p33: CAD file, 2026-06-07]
model/gearReducer/obj3.step
67.9 x 78.4 x 38.0 mm

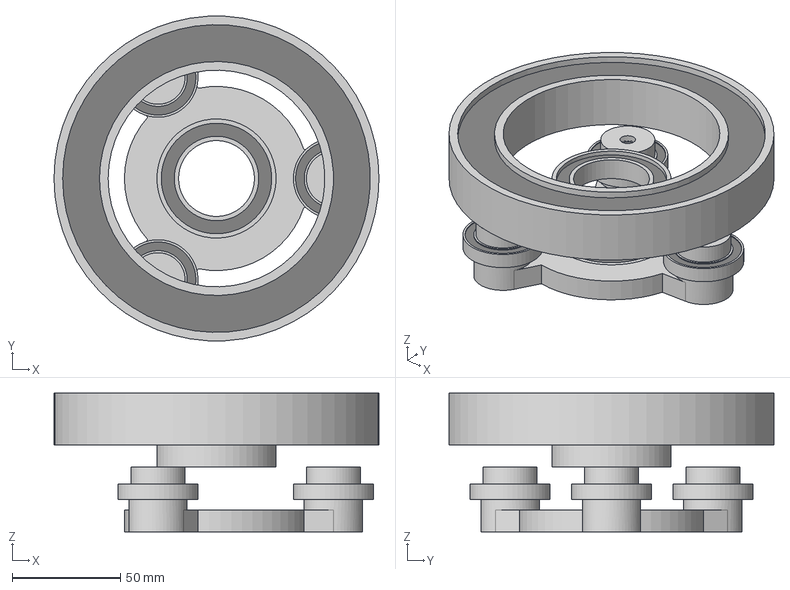
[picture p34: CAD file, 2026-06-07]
model/gearReducerOutput/obj1.step
150.0 x 149.8 x 64.0 mm

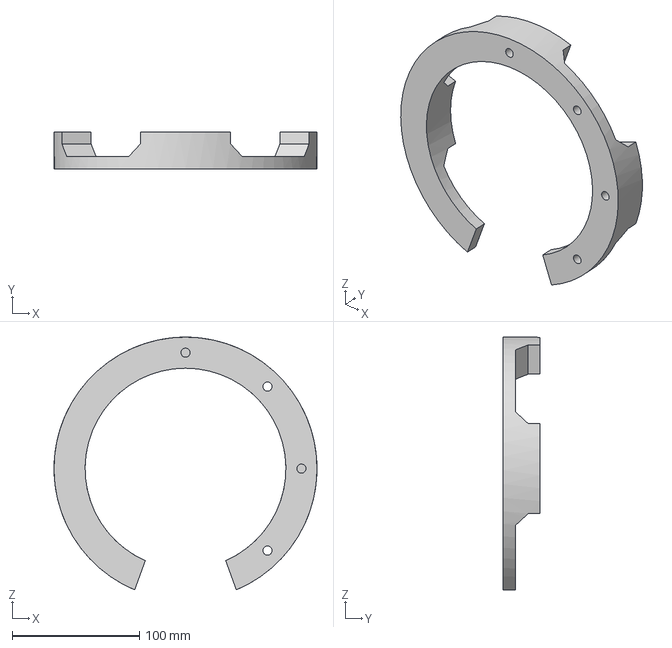
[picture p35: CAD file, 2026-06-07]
model/limb/obj9.step
207.0 x 29.5 x 199.0 mm

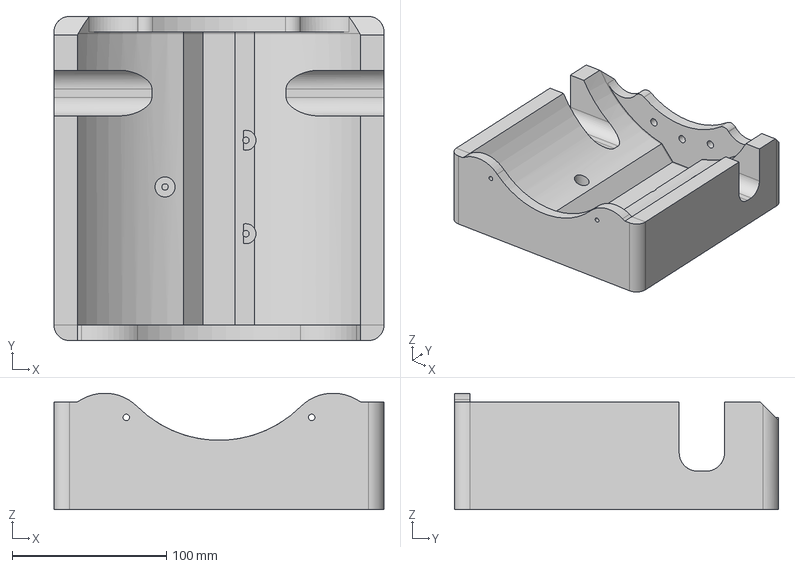
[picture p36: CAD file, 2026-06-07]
model/base/obj4.step
214.0 x 210.2 x 75.5 mm

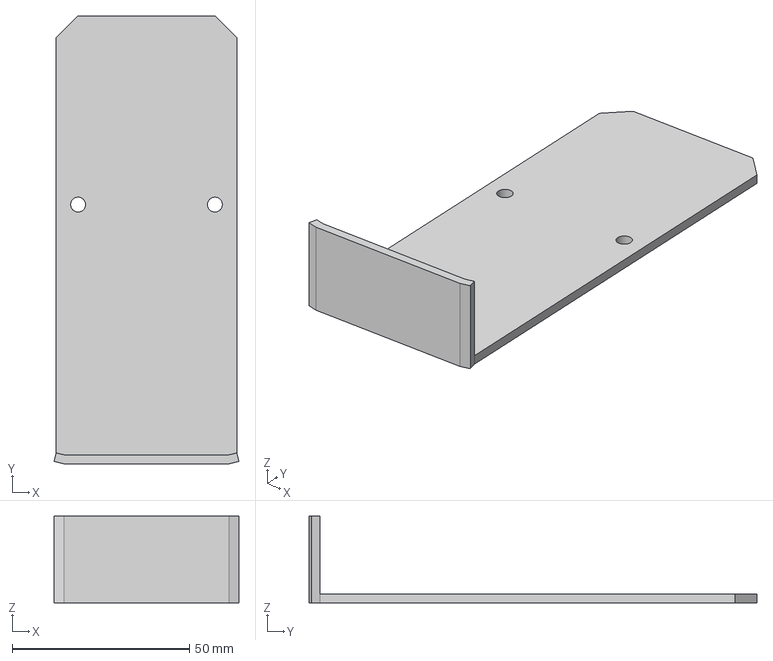
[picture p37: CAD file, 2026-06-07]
model/gearBox/obj3.step
52.2 x 126.3 x 24.4 mm

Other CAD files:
model/base/obj9.step
model/gearReducer/obj2.step
model/gearReducerOutput/obj2.step
model/limb/obj3.step
model/base/obj1.step
model/base/obj2.step
model/base/obj5.step
model/base/obj6.step
model/base/obj7.step
model/gearBox/obj7.step
model/gearReducer/gear_27teeth.step
model/gearReducer/obj4.step
model/gearReducerOutput/gear_27teeth.step
model/hand/obj1.step
model/hand/obj2.step
model/limb/limb13.step
model/limb/obj1.step
model/limb/obj11.step
model/limb/obj12.step
model/limb/obj15.step
model/limb/obj4.step
model/limb/obj5.step
model/limb/obj7.step
model/limb/obj8.step

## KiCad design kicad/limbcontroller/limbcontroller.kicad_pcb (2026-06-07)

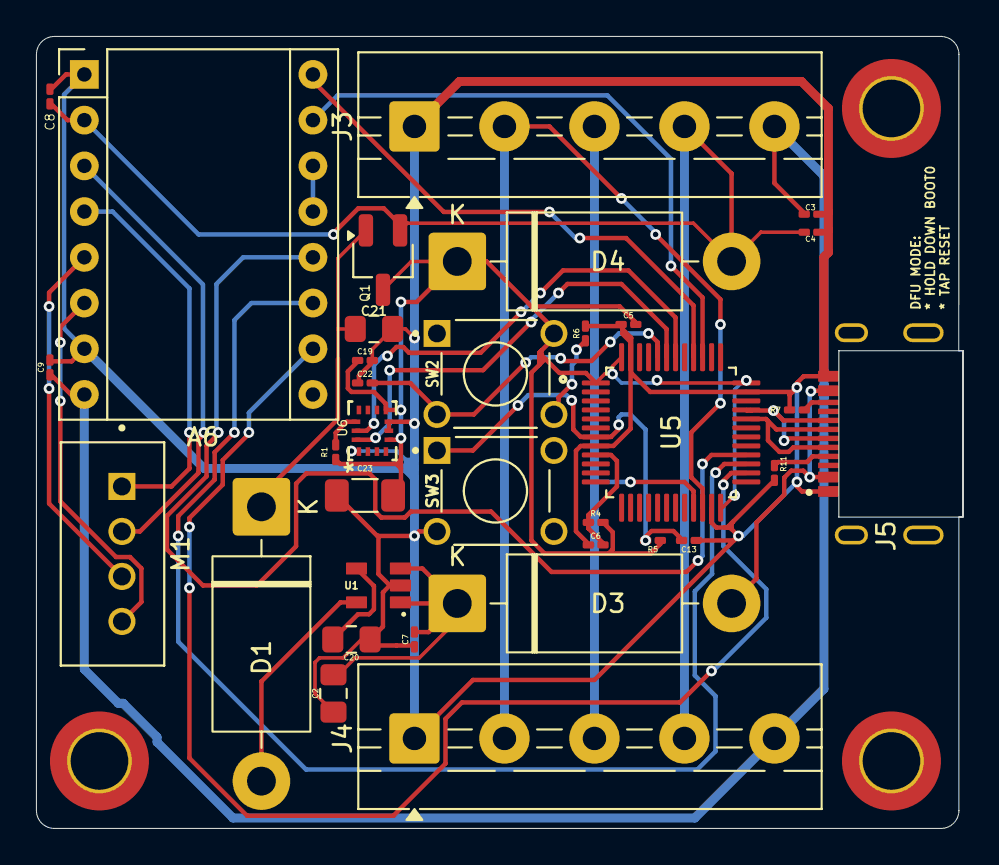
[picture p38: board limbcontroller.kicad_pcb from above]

Board: 2 copper layers, 51.5 x 44.0 mm, 34 parts (0 on the bottom side), 32 nets.

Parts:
A6: Pololu_Breakout_A4988; Pololu_Breakout-16_15.2x20.3mm
C2, C21: 1uF; C_0805_2012Metric_Pad1.18x1.45mm_HandSolder
C3, C4, C5, C6, C8, C9, C13, C19, C22: 0.1uF; C_0201_0603Metric_Pad0.64x0.40mm_HandSolder
C7: 10uF; C_0201_0603Metric_Pad0.64x0.40mm_HandSolder
C20: 22uF; C_0805_2012Metric_Pad1.18x1.45mm_HandSolder
C23: 0.01uF; C_1206_3216Metric_Pad1.33x1.80mm_HandSolder
D1, D3, D4: 1N5821; D_DO-201AD_P15.24mm_Horizontal
J3, J4: Screw_Terminal_01x05; TerminalBlock_MaiXu_MX126-5.0-05P_1x05_P5.00mm
J5: USB_C_Receptacle_USB2.0_14P; 2340901-1
M1: Stepper_Motor_bipolar; JST_B4B-XH-A
Q1: DTB143EK
R1: 100kΩ; R_0201_0603Metric_Pad0.64x0.40mm_HandSolder
R4: 470Ω; R_0201_0603Metric_Pad0.64x0.40mm_HandSolder
R5, R6: 10kΩ; R_0201_0603Metric_Pad0.64x0.40mm_HandSolder
R7, R11: 5.1kΩ; R_0201_0603Metric_Pad0.64x0.40mm_HandSolder
SW2, SW3: 1825910-6; SW_1825910-6-4
U1: RT9193-33GB; RT9193-SOT94P279X129-5N
U5: STM32F103C8T6; STM32F103-QFP50P900X900X160-48N
U6: BMI323; BMI323_BOS

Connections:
+3.3V: C5.2, C22.2, C23.2, D4.1 (K), Q1.C, R1.1, R4.1, R5.1, SW2.2, U5.1 (VBAT), U5.24 (VDD), U5.36 (VDD), U5.48 (VDD), U6.5 (VDDIO), U6.8 (VDD)
/VCC: A6.2 (VDD), C4.1, C8.1, D4.2 (A), J3.4, J4.4, Q1.B
/VMOT: A6.8 (VMOT), C3.1, C9.2, J3.5, J4.5
D+: J5.A6 (D+), J5.B6 (D+), U5.33 (PA12)
D-: J5.A7 (D-), J5.B7 (D-), U5.32 (PA11)
DIR: A6.16 (DIR), U5.40 (PB4)
GND: A6.1 (GND), A6.7 (GND), C2.1, C3.2, C4.2, C5.1, C6.1, C7.1, C8.2, C9.1, C13.1, C19.1, C20.1, C21.1, C22.1, C23.1, J3.1, J4.1, J5.A1/B12 (GND), J5.B1/A12 (GND), R6.2, R7.2, R11.1, SW3.3, U1.2 (GND), U5.8 (VSSA), U5.23 (VSS), U5.35 (VSS), U5.47 (VSS), U6.1 (SDO), U6.6 (GNDIO), U6.7 (GND)
MS1: A6.10 (MS1), U5.26 (PB13)
MS2: A6.11 (MS2), U5.27 (PB14)
MS3: A6.12 (MS3), U5.28 (PB15)
unnamed: A6.4 (1A), M1.1
unnamed: A6.3 (1B), M1.2 (-_2)
unnamed: A6.5 (2A), M1.3
unnamed: A6.6 (2B), M1.4
unnamed: A6.13 (~RESET), A6.14 (~SLEEP)
unnamed: D1.2 (A), U1.5 (VOUT)
unnamed: C21.2, D1.1 (K), Q1.E
unnamed: D3.2 (A), J5.A4/B9 (VBUS), J5.B4/AP (VBUS)
unnamed: C2.2, C7.2, D3.1 (K), U1.1 (VIN), U1.3 (EN)
unnamed: J5.A5 (CC1), R11.2
unnamed: J5.B5 (CC2), R7.1
unnamed: R6.1, SW2.4
unnamed: C20.2, U1.4 (BP)
unnamed: C19.2, SW2.3, U5.44 (BOOT0)
unnamed: C13.2, R5.2, SW3.1, U5.7 (NRST)
unnamed: C6.2, R4.2, U5.9 (VDDA)
unnamed: R1.2, U6.12 (CSB)
SCL: J3.3, J4.3, U5.21 (PB10)
SCL2: U5.42 (PB6), U6.13 (SCX)
SDA: J3.2, J4.2, U5.22 (PB11)
SDA2: U5.43 (PB7), U6.14 (SDX)
STEP: A6.15 (STEP), U5.39 (PB3)

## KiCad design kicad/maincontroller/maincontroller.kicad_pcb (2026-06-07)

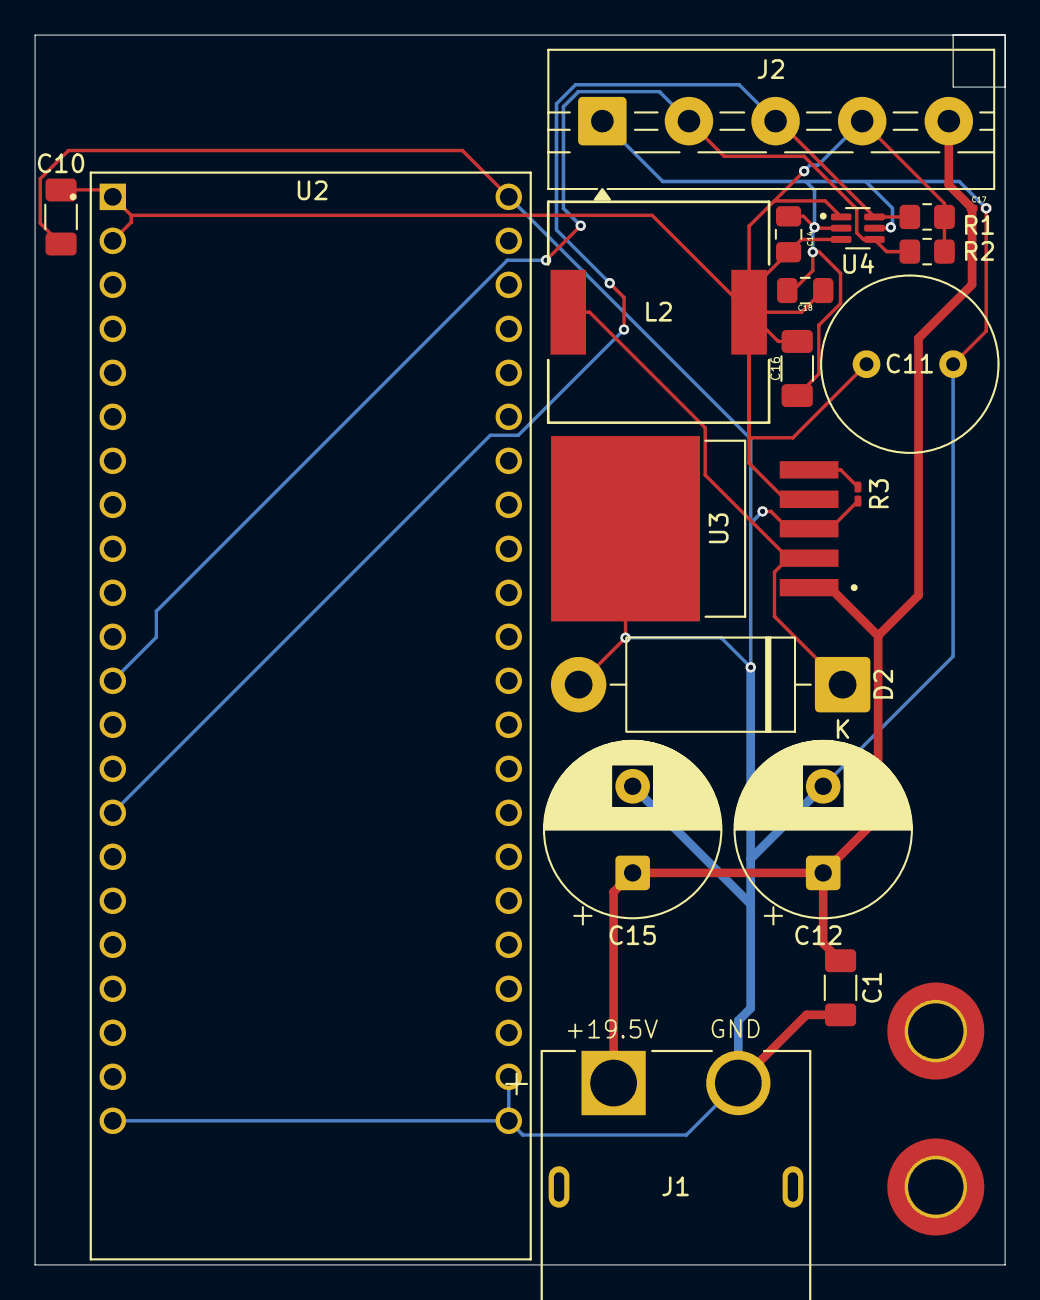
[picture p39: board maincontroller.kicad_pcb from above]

Board: 2 copper layers, 56.0 x 71.0 mm, 19 parts (0 on the bottom side), 7 nets.

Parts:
C1, C10, C16: 0.01uF; C_1206_3216Metric_Pad1.33x1.80mm_HandSolder
C11: 220uF; C_Radial_D10.0mm_H20.0mm_P5.00mm
C12, C15: 680uF; CP_Radial_D10.0mm_P5.00mm
C14, C18: 1uF; C_0805_2012Metric_Pad1.18x1.45mm_HandSolder
C17: 10uF; C_0201_0603Metric_Pad0.64x0.40mm_HandSolder
D2: 1N5821; D_DO-201AD_P15.24mm_Horizontal
J1: XT60PW-M; AMASS_XT60PW-M
J2: Screw_Terminal_01x05; TerminalBlock_MaiXu_MX126-5.0-05P_1x05_P5.00mm
L2: 33uH; IND_DR127-330-R_EAT
R1, R2: 4kΩ; R_0805_2012Metric_Pad1.20x1.40mm_HandSolder
R3: 10kΩ; R_0201_0603Metric_Pad0.64x0.40mm_HandSolder
U2: ESP32-S3-DEVKITC-1-N8R2; XCVR_ESP32-S3-DEVKITC-1-N8R2
U3: LM2596S-3.3_NOPB; VREG_LM2596S-3.3_NOPB
U4: LTC4311ISC6_TRPBF; LTC4311-SOT65P210X100-6N

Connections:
+3.3V: C10.1, C11.1, C14.1, C16.1, C18.1, J2.4, L2.2, R1.1, R2.1, U2.J1_1 (3V3), U2.J1_2 (3V3), U3.4 (FB), U4.1 (VCC), U4.3 (ENABLE)
+19.5V: C1.1, C12.1, C15.1, C17.1, J1.1, J2.5, U3.1 (VIN)
GND: C1.2, C10.2, C11.2, C12.2, C14.2, C15.2, C16.2, C17.2, C18.2, D2.2 (A), J1.2 (N), J2.1, R3.2, U2.J1_22 (GND), U2.J3_1 (GND), U2.J3_21 (GND), U2.J3_22 (GND), U3.3 (GND), U3.6 (GND), U4.2 (GND), U4.5 (GND)
unnamed: D2.1 (K), L2.1, U3.2 (OUT)
unnamed: R3.1, U3.5 (~ON/OFF)
SCL: J2.3, R1.2, U2.J1_15 (GPIO9), U4.6 (BUS1)
SDA: J2.2, R2.2, U2.J1_12 (GPIO8), U4.4 (BUS2)

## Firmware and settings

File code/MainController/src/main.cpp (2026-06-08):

#include <Arduino.h>
#include <Wire.h>

#define I2C_SCL_MAIN 9
#define I2C_SDA_MAIN 8
#define G_SENSITIVITY = 2

#define STEPS_PER_REVOLUTION 200

TwoWire mainI2C = TwoWire(0);

//kalman filter stuff
double Q_angle = 0.001;  // Process noise variance for the accelerometer
double Q_bias = 0.003;   // Process noise variance for the gyroscope bias
double R_measure = 0.03; // Measurement noise variance
unsigned long progTime = 0;

const int8_t X_IMU = 1;
const int8_t Y_IMU = 2;
const int8_t Z_IMU = 3;

#define LIMB_TYPE 1
#define BASE_TYPE 2
#define HAND_TYPE 3

struct IMUOrientation { 
    /* assuming positive X is facing left, positive Y is facing front, and Z is facing down
        negative values indicate the opposite direction. The orientation of the BMI323
        is assumed to be facing the white dot from above at the top left, with the left 
        of the dot being left (+X) and the forward from the dot being front (+Y). */
    int8_t xDirection, yDirection, zDirection; 
};
class Motor {
    public:
        uint8_t address;
        uint8_t angleAddress;
        IMUOrientation angleCarrierOrientation; /* rearranges sensor values to be relative to
                                                the arm as a whole (front is mostly arbitrary, yaw is not measured)
                                                uses the angles tracked from angleAddress*/
        uint8_t type = LIMB_TYPE;
        double pitch, roll = 0; // radians
        double bias, rate = 0;
        double P[2][2] = {{0,0}, {0, 0}};
        Motor(
            uint8_t address,
            uint8_t angleAddress, // address to query for current angle of actuator
            IMUOrientation angleCarrierOrientation,
            uint8_t type = LIMB_TYPE
        ){
            this->address = address;
            this->angleCarrierOrientation = angleCarrierOrientation;
            this->type = type;
        }
        // returns a bool of whether message was successfully sent, function does not work if the class represents the angle tracker for the hand
        bool moveAngle(
            double angle, // radians to rotate, negative will indicate counterclockwise
            int16_t stepOffset = 0,
            double gearRatio = 1.0/49 // 1:gearRatio -- a gearRatio above one means outputting less torque and more speed, vice cersa (for this project always equals 1/49)
        ){
            if(this->type == HAND_TYPE){ // preventing the angle sensor for the hand to be tracked
                return false;
            };
            int16_t numSteps = STEPS_PER_REVOLUTION*angle/(2*PI*gearRatio);
            //sends a int16_t num of steps to take, positive & negative included
            mainI2C.beginTransmission(this->address);
            mainI2C.write(numSteps + stepOffset);
            mainI2C.endTransmission();
            return true;
        }
};

// The base (the one marked BASE_TYPE) tracks its own angle, and Limb1's angle is tracked by Motor2's angle and Limb2 by Motor3.
// The hand is tracked by a motorless board designated HAND_TYPE
// However, Motor1 controls Limb1's angle, Motor2 controls Limb2's angle and Motor3 controls the Hand's angle. The base motor 
// only alters the yaw of the arm.
const uint8_t numLimbs = 5;
Motor motorList[numLimbs] = { // in order of connection from base to hand
    Motor(0x50, 0x50, {-Y_IMU, -X_IMU, -Z_IMU}, BASE_TYPE), //Base Motor
    Motor(0x51, 0x50, {-Y_IMU, -X_IMU, -Z_IMU}), //Motor 1
    Motor(0x52, 0x52, {-Z_IMU, X_IMU, -Y_IMU}), //Motor 2
    Motor(0x53, 0x53, {-Z_IMU, X_IMU, -Y_IMU}), //Motor 3
    Motor(0x54, 0x54, {-X_IMU, Z_IMU, Y_IMU}, HAND_TYPE) //Hand
};

//------

//all angles are radians from the horizontal up; 0 or pi radians means arm is flat 
double Kalman_filter(Motor *limb, double angle, double gyroRate, double accelAngle, double dt);

void sendCommand(
    double baseAngle,
    double limb1Angle,
    double limb2Angle,
    double handAngle
){
    for(int i = 0; i < 4; i++){
        double selectedAngle = 
            i == 0 ? baseAngle :
            i == 1 ? limb1Angle :
            i == 2 ? limb2Angle :
            i == 3 ? handAngle :
            PI/2;
        if(selectedAngle < 0 || selectedAngle > PI) continue;
        double offset = i == 2 ? -limb1Angle :
                        i == 3 ? limb2Angle : 0;
        motorList[i].moveAngle(selectedAngle - motorList[i].pitch + offset);
    }
}
void rearrangeIMUOutput(
    double *directionVector, // intended to be in order of X, Y and Z values
    uint8_t numRead,
    int16_t value, 
    IMUOrientation imuOrient 
    /* IMUOrientation tells us which of the sensor's directions correspond to the arm's direction, 
        eg. if xDirection = -Z_IMU that means that perceived from the perspective of the arm,
        the X (left) acceleration/gyroscope sensor value would be the negative of the acceleration 
        value read from the Z axis of the IMU
    */
    /* the numRead corresponds to whether the X, Y or Z sensor was read
    */
){
    if(abs(imuOrient.xDirection) == numRead){
        directionVector[0] = value * (imuOrient.xDirection < 0 ? -1 : 1); 
    } else if(abs(imuOrient.yDirection) == numRead) {
        directionVector[1] = value * (imuOrient.yDirection < 0 ? -1 : 1); 
    } else if(abs(imuOrient.zDirection) == numRead) {
        directionVector[2] = value * (imuOrient.zDirection < 0 ? -1 : 1); 
    }
}
void fetchAngles(){
    for(int i = 0; i < numLimbs; i++){
        double accel[3]; //xyz format
        double gyro[3]; //xyz format
        Motor motor = motorList[i];
        mainI2C.requestFrom(motor.angleAddress, 16*6); // order sent: accel_x, accel_y, accel_z, gyro_x, gyro_y, gyro_z
        uint8_t integersRead = 0;                         // since 6 signed 16 bit integers are sent, we expect to read 12 bytes
        while(mainI2C.available() >= 2 && integersRead < 6 ){
            integersRead++;
            byte msb = mainI2C.read();
            byte lsb = mainI2C.read();
            int16_t num = (msb << 8) | lsb;
            rearrangeIMUOutput(
                integersRead <= 3 ? accel : gyro,
                integersRead,
                num,
                motor.angleCarrierOrientation
            );
        }
        double dt = (millis() - progTime)/1000.0;
        dt = dt <= 0 ? 0.001 : dt;
        progTime = millis();

        // original function:
        // pitch = Kalman_filter(pitch, gx, atan2(-ax, sqrt(ay * ay + az * az)) * 180.0 / PI);
        // roll = Kalman_filter(roll, gy, atan2(ay, az) * 180.0 / PI);
        // in the blog X is front and Y is left, therefore here pitch and roll are switched
 
        motor.roll = Kalman_filter(&motor, motor.roll, gyro[0], atan2(-accel[0], sqrt(accel[1] * accel[1] + accel[2] * accel[2])) * 180.0 / PI, dt);
        motor.pitch = Kalman_filter(&motor, motor.pitch, gyro[1], atan2(accel[1], accel[2]) * 180.0 / PI, dt);
    }
}

void setup() {
    mainI2C.begin(I2C_SDA_MAIN, I2C_SCL_MAIN, 100000);
    progTime = millis();
}

bool hasRunTest = false;
void loop() {
    // all funcs below
    // ...
    if(!hasRunTest && millis() > 8000){
        sendCommand(
            PI/8,
            PI/2,
            0,
            0
        );
        hasRunTest = true;
    }
    fetchAngles();
    delay(10);
}

// borrowed code from https://how2electronics.com/measure-pitch-roll-yaw-with-mpu6050-hmc5883l-esp32/
double Kalman_filter(Motor *limb, double angle, double gyroRate, double accelAngle, double dt) {
  limb->rate = gyroRate - limb->bias;
  angle += dt * limb->rate;
 
  limb->P[0][0] += dt * (dt * limb->P[1][1] - limb->P[0][1] - limb->P[1][0] + Q_angle);
  limb->P[0][1] -= dt * limb->P[1][1];
  limb->P[1][0] -= dt * limb->P[1][1];
  limb->P[1][1] += Q_bias * dt;
 
  // Update
  double S = limb->P[0][0] + R_measure; // Estimate error
  double K[2];                    // Kalman gain
  K[0] = limb->P[0][0] / S;
  K[1] = limb->P[1][0] / S;
 
  double y = accelAngle - angle; // Angle difference
  angle += K[0] * y;
  limb->bias += K[1] * y;
 
  double P00_temp = limb->P[0][0];
  double P01_temp = limb->P[0][1];
 
  limb->P[0][0] -= K[0] * P00_temp;
  limb->P[0][1] -= K[0] * P01_temp;
  limb->P[1][0] -= K[1] * P00_temp;
  limb->P[1][1] -= K[1] * P01_temp;
 
  return angle;
}

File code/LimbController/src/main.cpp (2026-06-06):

#include <Arduino.h>
#include <Wire.h>

/* Alter the two parameters below based on which device is being flashed.
* Only set "isHand" to true if flashing to the board meant for tracking the hand's angle (the one not attached to any motor)
* Note that an A4988 motor stepper driver is needed only for non-hand controllers
*/
/* UNIQUE address for each limb, change 
    in each limb and main controller accordingly 
    Addresses for each limb:
    * BaseMotor : 0x50
    * Motor1 : 0x51
    * Motor2 : 0x52
    * Motor3 : 0x53
    * Hand : 0x54
*/
/* --------------------------- */
const uint8_t LIMB_I2C_ADDRESS = 0x50; 
const bool isHand = false;
/* --------------------------- */

#define STEP_PIN 39
#define DIR_PIN 40
#define I2C_SCL_SUB 42
#define I2C_SDA_SUB 43
#define I2C_SCL_MAIN 21
#define I2C_SDA_MAIN 22
#define MS1_PIN 26
#define MS2_PIN 27
#define MS3_PIN 28

#define INC_ADDRESS 0x68
#define ACC_CONF  0x20  //Page 91
#define GYR_CONF  0x21  //Page 93
#define CMD       0x7E  //Page 65

#define ACC_DATA_X_ADDR 0x03 
#define ACC_DATA_Y_ADDR 0x04
#define ACC_DATA_Z_ADDR 0x05

const int COMMAND_BUFFER_MAX = 20;
const double gearRatio = 1/49;
const int stepsPerRevolution = 200;

TwoWire mainI2C(I2C_SDA_MAIN, I2C_SCL_MAIN);
TwoWire subI2C(I2C_SDA_SUB, I2C_SCL_SUB);
I2C_HandleTypeDef hi2c1; //I2C main     
I2C_HandleTypeDef hi2c2; //I2C sub

// angle data
int16_t commandBuffer[COMMAND_BUFFER_MAX];
int16_t  x, y, z;
int16_t  gyro_x, gyro_y, gyro_z;
bool isTurning = false;

void handleMainCommand(int numBytes){
    shiftCommands();
    uint8_t buffer[numBytes];
    mainI2C.readBytes(buffer, numBytes);
    int16_t steps = (buffer[0] << 8) | buffer[1];
    for(int i = 0; i < COMMAND_BUFFER_MAX; i++){
        if(commandBuffer[i] == 0){
            commandBuffer[i] = steps;
            break;
        }
    }
}
void handleData(){
    mainI2C.write(x);
    mainI2C.write(y);
    mainI2C.write(z);
    mainI2C.write(gyro_x);
    mainI2C.write(gyro_y);
    mainI2C.write(gyro_z);
}

// below is borrowed code from https://forum.arduino.cc/t/bmi323-sensor-with-i2c-kalman-filter/1225900 for the BMI323
//Read all axis
void readAllAccel() {
  Wire.beginTransmission(INC_ADDRESS);
  Wire.write(0x03);
  Wire.endTransmission();
  Wire.requestFrom(INC_ADDRESS, 20);
  uint16_t data[20];
  int i = 0;
  while(Wire.available()){
    data[i] = Wire.read();
    i++;
  }
  int offset = 0;  
  x =             (data[offset + 0]   | (uint16_t)data[offset + 1] << 8);  //0x03
  y =             (data[offset + 2]   | (uint16_t)data[offset + 3] << 8);  //0x04
  z =             (data[offset + 4]   | (uint16_t)data[offset + 5] << 8);  //0x05
  gyro_x =         (data[offset + 6]   | (uint16_t)data[offset + 7] << 8);  //0x06
  gyro_y =         (data[offset + 8]   | (uint16_t)data[offset + 9] << 8);  //0x07
  gyro_z =         (data[offset + 10]  | (uint16_t)data[offset + 11] << 8); //0x08
//   temperature =   (data[offset + 12]  | (uint16_t)data[offset + 13] << 8); //0x09
//   temperatureInDegree = (temperature/512.f) + 23.0f;  
}
void softReset(){  
  writeRegister16(&subI2C, CMD, 0xDEAF);
  delay(50);    
}

void writeRegister16(TwoWire *wire, uint16_t reg, uint16_t value) {
  wire->beginTransmission(INC_ADDRESS);
  wire->write(reg);
  //Low
  wire->write((uint16_t)value & 0xff);
  //High
  wire->write((uint16_t)value >> 8);
  wire->endTransmission();
}

uint16_t readRegister16(TwoWire *wire, uint8_t reg) {
  wire->beginTransmission(INC_ADDRESS);
  wire->write(reg);
  wire->endTransmission(false);
  int n = wire->requestFrom(INC_ADDRESS, 4); 
  uint16_t data[4];
  int i =0;
  while(wire->available()){
    data[i] = Wire.read();
    i++;
  } 
  return (data[3] | data[2] << 8);
}
// ------------------------------------

void setup(){
    mainI2C.begin(LIMB_I2C_ADDRESS);
    mainI2C.setClock(100000);
    
    if(!isHand){
        subI2C.begin();
        subI2C.setClock(100000);
        pinMode(STEP_PIN, OUTPUT);
        pinMode(DIR_PIN, OUTPUT);
    }
    
    writeRegister16(&subI2C, 0x20, 0x4007); //accelerometer init, the N in 0x__N_ determines sensitivity
    writeRegister16(&subI2C, 0x21, 0x404B); //gyroscope init

    mainI2C.onReceive(handleMainCommand);
    mainI2C.onRequest(handleData);
}
void shiftCommands(){
    int offset = 0;
    for(int i = 0; i < COMMAND_BUFFER_MAX; i++){
        if(commandBuffer[i] == 0){
            offset++;
        } else {
            break;
        }
    }
    if(offset >= COMMAND_BUFFER_MAX) return;
    for(int i = 0; i < COMMAND_BUFFER_MAX-offset; i++){
        commandBuffer[i] = commandBuffer[i+offset];
    }
}

const int maxRPM = 200;
const double maxStepVelocity = ((double)maxRPM*stepsPerRevolution)/(60.0*1000); // units: steps per millisecond
const double stepAcceleration = 0.0001; // step per millisecond^2, 
const double timeToMaxVelocity = maxStepVelocity/stepAcceleration; //milliseconds
double stepVelocity = 0; // step per millisecond, is always positive
bool isDirectionHigh = false; // direction
bool isDeaccelerating = false;
uint32_t time = millis(); 

int stepDeaccelerationCutoff() {
    return (int)(stepVelocity*stepVelocity)/(2*stepAcceleration);
}
void loop(){
    if(readRegister16(&subI2C, 0x02) == 0x00){
        readAllAccel();
    }
    if(!isHand){
        if(commandBuffer[0] != 0){
            if(commandBuffer[0] < 0 == !isDirectionHigh){ // check if direction is set correctly, if not set the correct one (negative steps are CCW)
                isDirectionHigh == !isDirectionHigh;
                digitalWrite(DIR_PIN, isDirectionHigh ? HIGH : LOW);
            }
            if(!isDeaccelerating && commandBuffer[0] < stepDeaccelerationCutoff()) { //deacceleration as limb approaches position
                isDeaccelerating = true;
            } else if(stepVelocity < maxStepVelocity){ //check if velocity is max, if not speed up w/ constant acceleration
                stepVelocity += stepAcceleration*(millis()-time);
                if(stepVelocity > maxStepVelocity) stepVelocity = maxStepVelocity;
            }
            if(isDeaccelerating) stepVelocity -= stepAcceleration;
        } else {
            stepVelocity = 0;
            isDeaccelerating = false;
            if(commandBuffer[1] != 0){
                shiftCommands();
            }
        }
        if(stepVelocity > 0 && millis() - time >= 1.0/stepVelocity && commandBuffer[0] > 0){ //stepping the motor if velocity and command exists
            digitalWrite(STEP_PIN, HIGH);
            commandBuffer[0]--;
        } else {
            digitalWrite(STEP_PIN, LOW);
        }
        if(stepVelocity < 0) stepVelocity = 0;
    }
    time = millis();
    delayMicroseconds(100);
}

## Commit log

2026-06-07 added CAD model images and files
    [gear_27teeth.step, limb13.step, obj1.step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]
2026-06-07 added pcb gerber files
    [limbcontroller-B_Cu.gbr, limbcontroller-B_Mask.gbr, limbcontroller-B_Paste.gbr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]
2026-06-07 cleaned up kicad files and changed 1uf capacitors to 0805 SMD size
    [limbcontroller-B_Cu.gbr, limbcontroller-B_Mask.gbr, limbcontroller-B_Paste.gbr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]
2026-06-07 added baseSunGear printables & diagram
    [obj1.step, obj2.step]
2026-06-08 updated project README.md and fixed main controller code
    [obj8.step, obj9.step]
2026-06-09 added zine
    [BOM.csv]
2026-06-09 clarified wiring in readme
2026-06-09 fixed missing B4B-XH-A in BOM
    [BOM.csv]
